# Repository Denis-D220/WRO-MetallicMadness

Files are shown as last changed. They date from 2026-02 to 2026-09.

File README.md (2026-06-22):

# MetallicMadness / ARBIBOT — WRO Future Engineers 2026

ARBIBOT on the WRO Future Engineers field

**MetallicMadness** is a WRO Future Engineers self-driving car project developed for the **WRO 2026 Future Engineers — Self-Driving Cars** challenge. The robot is named **ARBIBOT**. It is an autonomous four-wheel vehicle that combines computer vision, time-of-flight distance sensing, embedded motor control, and a modular software architecture to complete the Open Challenge and Obstacle Challenge tasks.

The project focuses on building a reproducible autonomous vehicle that can drive several laps on the WRO racetrack, follow the correct driving direction, react to red and green traffic signs, avoid moving obstacles, and support parking behavior. The design uses a high-level AI processor for perception and navigation decisions, and a low-level STM32 controller for real-time motor control, sensor acquisition, and encoder feedback.

This repository contains the source code, engineering journal, wiring references, subsystem images, sensor and motor-control documentation, and supporting files required to understand, rebuild, and evaluate the robot.

---

## Team Information

| Item | Information |
|---|---|
| Team name | MetallicMadness |
| Robot name | ARBIBOT |
| Competition | WRO Future Engineers — Self-Driving Cars |
| Institution | Universidad Metropolitana, Caracas |
| Country | Venezuela |
| Team member | Daniel Jose Denis Castillo |
| Team member | Douglas Gabriel Ordaz Yanez |
| Tutor / Coach | Daniel Jose Denis Rodriguez |

### Team Members

**Daniel Jose Denis Castillo** is an Electrical Engineering student at Universidad Metropolitana in Caracas. He has a strong passion for electronics, robotics, Python programming, AI models, and practical problem solving. His work in this project focuses on embedded systems, robot integration, testing, and autonomous behavior.

**Douglas Gabriel Ordaz Yanez** is studying Electrical Engineering and Computer Engineering at Universidad Metropolitana in Caracas. He has a strong interest in software development, game programming, coding logic, and digital systems. His contribution focuses on programming logic, testing, software structure, and implementation support.

**Daniel Jose Denis Rodriguez**, the tutor, is an Electrical Engineer from Universidad Metropolitana with more than 25 years of experience in software engineering, telecommunications, AI, cybersecurity, embedded systems, and technology leadership. His role is to guide the students in project planning, engineering reasoning, documentation, and technical review.

---

## Project Goals

The main goal of ARBIBOT is to create an autonomous self-driving robot that can complete the WRO Future Engineers track using a combination of computer vision, ToF distance sensors, and embedded motor control.

The robot was designed around the following engineering goals:

1. **Autonomous driving:** the vehicle must drive without remote control or wireless assistance during the round.
2. **Stable lane behavior:** the robot must stay aligned with the track walls using distance sensors and heading correction.
3. **Obstacle strategy:** the robot must recognize red and green traffic signs and pass them on the correct side.
4. **Reliable embedded control:** motor, encoder, and sensor operations must be handled by a dedicated STM32 controller.
5. **High-level perception:** the Jetson Orin Nano processes camera input and runs YOLO-based detection models.
6. **Reproducibility:** the repository and engineering journal must allow another team to understand and rebuild the system with reasonable effort.
7. **Iteration and testing:** the project documents failures, design changes, and improvements made during development.

---

## Repository Structure

```text
WRO-MetallicMadness/
├── README.md
├── engineering-journal/
│   ├── README.md
│   ├── engineering-journal.md
│   ├── engineering-journal.pdf
│   └── images/
├── src/
│   ├── NVIDIA/
│   └── STM32F411/
├── schemes/
├── models/
├── t-photos/
├── v-photos/
├── video/
└── other/
```

### Folder Purpose

| Folder | Purpose |
|---|---|
| `engineering-journal/` | Main engineering documentation in Markdown and PDF format, including images and system explanations. |
| `src/NVIDIA/` | Python code running on the NVIDIA Jetson Orin Nano, including vision, navigation, serial communication, and steering control. |
| `src/STM32F411/` | STM32 firmware for motor control, distance sensor acquisition, encoder feedback, IMU reading, and DD-UART command handling. |
| `schemes/` | Wiring diagrams, power diagrams, system block diagrams, and subsystem architecture references. |
| `models/` | CAD, mechanical models, 3D printed parts, AI model notes, or model references used by the project. |
| `t-photos/` | Team photos required for WRO documentation. |
| `v-photos/` | Vehicle photos from all required views: front, rear, left, right, top, and bottom. |
| `video/` | Links or notes for Open Challenge and Obstacle Challenge autonomous driving videos. |
| `other/` | Additional supporting files such as datasheets, testing notes, calibration references, and protocol details. |

---

## Robot Overview

ARBIBOT is a compact 3D-printed autonomous vehicle using rear-wheel drive and front-wheel steering. The mechanical design follows the WRO requirement of a four-wheel vehicle with one driving axle and one steering actuator. The robot uses a custom front steering linkage and a single DC gear motor with an encoder for propulsion.

### Physical Characteristics

| Parameter | Value |
|---|---:|
| Length | 25 cm |
| Width | 15.6 cm |
| Height | 18 cm |
| Weight | 1.35 kg |
| Wheelbase | 13.9 cm |
| Track width | TODO: measure and fill |
| Chassis | 3D printed |
| Drive configuration | Rear-wheel drive |
| Steering | Servo-actuated pushrod steering with tie-rod linkage |

The steering system uses a servo arm to push and pull a linkage connected to the front steering knuckle. Both front wheels are mechanically connected by a tie rod, so the motion of one wheel is transferred to the other. This creates a synchronized front-wheel steering system using only one steering actuator. The geometry is Ackermann-inspired, but it is documented as a custom servo-driven pushrod/tie-rod linkage unless precise steering angle measurements are added later.

The 3D-printed chassis was selected because it allows fast mechanical iteration. Several bumper versions and sensor positions were tested. Early bumper designs created interference with the wheels while turning, so the front structure and sensor mounts were adjusted. The team also tested thinner wheels, but they slipped on the track, so wider wheels with better grip were selected.

---

## Mechanical Design

### Chassis

The robot uses a 3D-printed chassis designed to hold the Jetson Orin Nano, STM32 controller, motor driver, batteries, distance sensors, camera mount, steering system, and wiring. The chassis design prioritizes modularity and easy access to subsystems during testing.

The mechanical structure was developed through iteration. Early versions had issues with sensor height, bumper clearance, and torque transfer. These issues were corrected by modifying the sensor mount height, changing bumper geometry, and improving the drivetrain layout.

### Drive Motor

The drive motor is a **JGY-370B 12V Mini Worm Gear Motor with Encoder**, configured for approximately **150 RPM** no-load speed. It is a double-shaft DC gear motor with Hall encoder feedback.

Key characteristics:

| Item | Value |
|---|---|
| Motor type | DC worm gear motor with encoder |
| Model | JGY-370B |
| Rated voltage | 12 V DC |
| Speed | 150 RPM |
| Encoder type | Hall AB quadrature output |
| Basic pulse count | 11 PPR before gearbox multiplication |
| Encoder voltage | 3.3 V / 5 V |
| Output signal | Square wave AB phase |
| Direction | Reversible CW / CCW |
| Gear material | Metal gears |

The worm gear motor was selected because it provides useful torque for a compact robot and has a self-locking behavior when power is removed. The encoder allows the STM32 to measure wheel movement and RPM. The project originally tested a motor without an encoder, but this limited feedback and made distance-based movement less reliable.

### Steering Actuator

The steering actuator is an **MG996R servo**.

| Parameter | Value |
|---|---|
| Model | MG996R |
| Voltage | 5 V |
| Torque | approximately 9.4 kg·cm at 4.8 V |
| Control | Pololu servo controller |

The steering linkage was tuned by adjusting rod lengths and servo arm geometry. The final adjustments use a screw-based alignment method to modify the distance between linkage points and improve front-wheel alignment. This was necessary to increase turning range and reduce unwanted steering bias.

---

## System Architecture

ARBIBOT uses a two-controller architecture:

1. **NVIDIA Jetson Orin Nano** — high-level perception, vision, navigation logic, and decision making.
2. **STM32F411 Black Pill** — low-level sensor acquisition, motor control, encoder reading, and serial command execution.

This separation allows the robot to keep time-critical motor and sensor operations on the STM32 while the Jetson handles heavier AI and image-processing tasks. This design also improves modularity: the Jetson can send high-level commands, while the STM32 safely executes motor and sensor routines.

```text
Camera + YOLO + Navigation Logic
              │
              ▼
     NVIDIA Jetson Orin Nano
              │  DD-UART over USB/Serial
              ▼
         STM32F411 Black Pill
              │
 ┌────────────┼─────────────┐
 ▼            ▼             ▼
Motor      ToF Sensors     Encoder / IMU
Driver
```

---

## NVIDIA Jetson Orin Nano Subsystem

The Jetson Orin Nano is the high-level processor used for AI inference, camera processing, autonomous decision making, and communication with the STM32. It was selected because it provides enough AI acceleration and computing capacity to run YOLO inference and OpenCV processing in real time while also managing navigation logic.

### Jetson Responsibilities

The Jetson runs:

- Camera capture through a CSI camera pipeline.
- YOLO inference using custom-trained models.
- Red and green pillar detection.
- Blue/orange line and corner detection.
- Lane and wall-following logic.
- Navigation decision logic.
- Command transmission to the STM32 through the custom DD-UART serial protocol.
- Steering commands through a Pololu servo controller.

### Camera

The camera is a **Mini 12.3MP HQ Camera compatible with NVIDIA Jetson boards**, using a **Sony IMX477** sensor and an M12 mount lens. It is connected directly to the Jetson through the MIPI CSI-2 camera connector.

The camera is used for:

- Detecting red and green pillars.
- Detecting blue and orange track lines.
- Estimating the horizontal position of objects.
- Supporting corner detection and driving direction logic.

YOLO is used instead of only color thresholding because the lighting conditions on the field can change. Reflections, shadows, glare, camera exposure, and partial occlusion can make simple HSV thresholds unstable. YOLO provides both object localization and classification, making it more robust for competition environments.

---

## STM32F411 Subsystem

The STM32F411 Black Pill acts as the real-time controller for peripheral devices. Its main purpose is to isolate low-level deterministic tasks from the Jetson so that motor control and sensor reading remain stable even while the Jetson performs heavier vision inference.

### STM32 Responsibilities

The STM32 handles:

- Reading VL53L4CD side distance sensors.
- Reading the front VL53L8CH ToF matrix sensor.
- Managing the I2C sensor bus.
- Using XSHUT pins to initialize multiple VL53L4CD sensors with different addresses.
- Reading motor encoder AB phases.
- Measuring RPM and movement distance.
- Driving the Cytron MD10C motor driver using PWM and direction signals.
- Processing serial commands from the Jetson.
- Returning sensor and motor responses through DD-UART.

The STM32 firmware is organized into modules for protocol handling, motor control, distance sensors, IMU, platform I2C layers, and the main command-dispatch loop.

---

## Sensor Architecture

The robot uses multiple ST time-of-flight distance sensors to measure the distance to walls, obstacles, and front barriers. The sensor system is designed to support wall following, obstacle distance estimation, side correction, and parking behavior.

### Distance Sensors

| Sensor | Quantity | Placement | Purpose |
|---|---:|---|---|
| VL53L4CD | 3 | left front, right front, right rear/middle | Side distance, wall following, side correction, obstacle distance, parking support |
| VL53L8CH | 1 | front bumper / center front | Front matrix distance, barrier detection, corner trigger support |

### Sensor Placement

| Sensor | Location | I2C Address | XSHUT Pin |
|---|---|---|---|
| Left VL53L4CD | Front bumper, left side | 0x52 | PA5 |
| Right-front VL53L4CD | Front bumper, right side | 0x54 | PA7 |
| Right-rear VL53L4CD | Middle of car, between wheels | 0x56 | PB14 |
| Front VL53L8CH | Front bumper / center | 0x52 | Dedicated initialization / bus handling |

The two right-side sensors are used for wall-following and heading correction. The difference between the right-front and right-rear readings indicates whether the robot is parallel to the wall. This helps prevent the robot from drifting across the lane.

The front VL53L8CH is used as a matrix-based distance sensor. It helps detect the front wall and supports corner timing by identifying when the robot is approaching a barrier. The logic uses filtered readings to avoid false triggers from floor cells or isolated noisy readings.

An I2C expansion board is used to simplify wiring, distribute power, and share the I2C bus cleanly between multiple sensors. Multiple VL53L4CD sensors require XSHUT-controlled startup so that the STM32 can assign or activate addresses without bus conflicts.

### Sensor Calibration

The sensors are calibrated using fixed reference distances:

```text
120 cm, 110 cm, 100 cm, 90 cm, 80 cm, 70 cm, 60 cm, 50 cm, 40 cm, 30 cm, 20 cm, 10 cm
```

A Python test script reads all sensors after moving the car to each reference distance. This helps identify offsets, unstable readings, and sensor placement issues. The calibration process is important because small sensor errors can produce steering oscillation or incorrect corner detection.

---

## Motor Driver and Encoder

The robot uses a **Cytron MD10C motor driver** to control the 12 V DC gear motor. The MD10C receives control signals from the STM32 and motor power from the 3S battery system through the BMS.

### MD10C Control

| Signal | Source | Purpose |
|---|---|---|
| PWM | STM32 PA6 / timer channel | Controls motor speed |
| DIR | STM32 GPIO | Controls motor direction |
| GND | STM32 common ground | Shared logic reference |
| VIN | Motor battery / BMS | Motor power input |
| Motor output | DC gear motor | Drives rear axle |

The motor encoder provides AB quadrature feedback to the STM32. The firmware uses encoder pulses to calculate movement distance for move-by-degrees commands and to estimate motor speed in RPM.

---

## Power Architecture

ARBIBOT uses separate power paths for motor power and Jetson/electronics power. This separation reduces the risk that motor noise or high-current motor peaks will reset the Jetson, STM32, sensors, or serial communication.

### Motor Power Path

The motor power path uses **3 × 18650 lithium-ion cells** with a **3S 20A BMS**. The BMS output feeds the Cytron MD10C motor driver directly. The MD10C then powers the 12 V DC gear motor.

| Item | Value |
|---|---|
| Battery type | 18650 lithium-ion cells |
| Cell nominal voltage | 3.7 V |
| Cell capacity | 1200 mAh |
| Series configuration | 3S |
| BMS | 3S 20A BMS |
| Motor driver | Cytron MD10C |
| Motor voltage | 12 V nominal system |

### Jetson and Electronics Power Path

The Jetson uses a separate **Waveshare UPS module** with support for charging and output at the same time. The UPS supports three 18650 lithium batteries and provides the output used to power the Jetson and related electronics.

| Item | Value |
|---|---|
| UPS module | Waveshare UPS module for 3 × 18650 cells |
| Battery support | 3 × 18650 lithium cells |
| Charger | 12.6 V / 2 A |
| Output | Battery series voltage, 5 V 5 A, 3.3 V 300 mA |
| Jetson input | 12 V |
| Camera power | Directly from Jetson CSI camera interface |
| Pololu servo controller power | From the UPS/electronics power path |

### Estimated Power Budget

| Component | Voltage | Typical Current | Peak Current | Notes |
|---|---:|---:|---:|---|
| Jetson Orin Nano | 12 V | workload-dependent | up to high AI workload range | Runs camera, OpenCV, and YOLO inference |
| STM32F411 | 3.3 V / 5 V input | about 10 mA at high CPU speed, depending on peripherals | low | Handles real-time control |
| MG996R steering servo | 5 V | 120–900 mA depending on load | 1.5–2.5 A stall | Steering load depends on wheel friction and linkage geometry |
| JGY-370B drive motor | 12 V | 0.06–0.3 A typical | 1.3–2.0 A stall | Peak occurs during acceleration or stall |
| VL53 sensors | 3.3 V | 15–25 mA each while ranging | sensor-dependent | Multiple ToF sensors active during navigation |
| Camera | Jetson CSI | powered by Jetson | powered by Jetson | Used for YOLO detection |

The expected runtime is approximately **20–30 minutes**, which is higher than the required **3-minute challenge round** duration. The practical design target is not only runtime, but also stable voltage during motor acceleration, steering peaks, and AI inference load.

---

## Software Architecture

The software is divided into high-level Jetson Python modules and low-level STM32 C firmware.

### Jetson Software Modules

| File | Role |
|---|---|
| `main_challenge_01_v4.py` | Open Challenge logic using camera corner detection, heading wall-following, and front ToF matrix corner trigger. |
| `main_challenge_02.py` | Obstacle Challenge logic using pillar YOLO and PDI pass-side steering. |
| `turn_models.py` | Corner detector and line model helper functions. |
| `Pillar_recognition.py` | Converts YOLO results into pillar detections with color, zone, area, and guidance logic. |
| `pillar_counter.py` | Debounced enter/exit counting per pillar color. |
| `pid_line_follower.py` | PID lane controller using difference and single-wall modes. |
| `sensor_distance_v3.py` | Side ToF and front matrix reader/parser. Reduces matrix readings to useful front-barrier distance. |
| `motor_driver.py` | DD-UART motor command wrapper. |
| `servo_controller.py` | Steering servo control through its serial interface. |
| `color_tuning.py` | Per-camera color correction for detection stability. |

### STM32 Firmware Modules

| File | Role |
|---|---|
| `serial_dd_protocol.c/.h` | Parses and validates DD-UART frames, verifies checksum, dispatches commands, and builds responses. |
| `motor_drv.c/.h` | Controls PWM, motor direction, move-by-degrees, encoder counting, and RPM calculation. |
| `sensor_vl53l4cd.c` | Reads side VL53L4CD ToF sensors. |
| `sensor_vl53l7ch.c` | Reads front VL53L7CX/VL53L8 matrix sensor. |
| `sensor_imu.c` | Reads gyro and accelerometer values. |
| `platform.c / platform2.c` | I2C platform layers for the ToF sensors. |
| `main.c` | Main command dispatch and system loop. |

---

## Navigation and Control Strategy

The robot uses a state-machine approach to organize behavior. The main states are:

```text
WAITING_FOR_START
FIRST_SECTOR
STRAIGHT_DRIVE
CORNERING
OBSTACLE_HANDLING
FINISH / STOP
```

### Open Challenge Strategy

In the Open Challenge, the robot drives without red or green pillars. The main navigation goal is to complete three laps while staying inside the lane and correctly detecting corners. The robot uses side ToF sensors to follow the wall and front ToF matrix readings to detect approaching barriers. Camera-based line/corner recognition supports driving direction and corner logic.

### Obstacle Challenge Strategy

In the Obstacle Challenge, the robot must detect red and green traffic signs and pass them on the correct side. The pillar YOLO model returns bounding boxes and classes for **Green_Pillar** and **Red_Pillar**. The robot uses the object class and horizontal location to decide the steering correction.

Rules used by the robot:

- Red pillar: pass on the right side.
- Green pillar: pass on the left side.

The system chooses the nearest relevant pillar using bounding-box area. Larger bounding boxes normally indicate that the pillar is closer. The robot divides the camera image into left, center, and right zones to estimate where the pillar is located relative to the car.

### Control Algorithms

The robot uses several control methods:

| Control method | Purpose |
|---|---|
| PID | Lane and wall-following correction. |
| PDI | Pillar pass-side steering correction. |
| Proportional heading correction | Uses right-front and right-rear ToF sensor difference to keep the robot parallel to the wall. |
| Threshold logic | Detects corner trigger windows and front barrier distance. |
| Sensor fusion | Combines camera, side ToF, and front matrix readings for more reliable navigation. |

---

## DD-UART Serial Protocol

The Jetson communicates with the STM32 using a custom binary protocol called **DD-UART**. This protocol is used to request sensor data, command motor actions, set speed, and stop the robot.

### Frame Format

```text
$ LEN(2 bytes, big-endian) CMD(2 bytes, big-endian) DATA(0..n) CHK(1 byte) \n
```

- `$` is the start byte.
- `LEN` is the total frame length.
- `CMD` is the command ID.
- `DATA` is the optional payload.
- `CHK` is an XOR checksum over the frame content between the start byte and checksum.
- `\n` is the end byte.

### Main Commands

| Command | Name | Payload | Purpose |
|---:|---|---|---|
| `0x0001` | READ_GYRO | none | Read IMU gyro data. |
| `0x0002` | READ_ACCEL | none | Read IMU acceleration data. |
| `0x0003` | READ_FRONT | none | Read front VL53L8/VL53L7 matrix. |
| `0x0004` | FORWARD continuous | none | Drive forward continuously. |
| `0x0005` | REVERSE continuous | none | Drive reverse continuously. |
| `0x0101` | FORWARD by degrees | uint16 degrees | Move forward by encoder-derived distance. |
| `0x0102` | REVERSE by degrees | uint16 degrees | Move reverse by encoder-derived distance. |
| `0x0103` | STOP | none | Stop drive motor. |
| `0x0104` | SET SPEED | uint8 percent | Set motor speed from 0 to 100%. |
| `0x0105` | READ SIDES | none | Read VL53L4CD side sensors. |

Because sensors and motor commands share one serial link, the Jetson avoids blocking motor commands while the sensor thread owns serial reads. Critical commands such as start and stop are sent multiple times to reduce the chance of a dropped frame affecting the run.

---

## Vision and YOLO Models

ARBIBOT uses Ultralytics YOLO with custom-trained weights. The vision system currently uses two model roles:

1. **Pillar model** for the Obstacle Challenge.
2. **Line/corner model** for the Open Challenge.

### Pillar Detection

The pillar model detects:

- `Green_Pillar`
- `Red_Pillar`

The output used by the navigation system includes:

- Class name.
- Bounding-box center X.
- Bounding-box area.
- Confidence.
- Zone: left, center, or right.

The area is used as an approximate closeness signal. The horizontal position is used to calculate steering error and guide the robot to pass the pillar on the correct side.

### Items Still To Be Completed

The following vision information should be added after measurement or review:

- Exact YOLO version.
- Dataset size per model.
- Annotation tool used.
- Training environment.
- Inference FPS on Jetson.
- Average inference time in milliseconds.
- Final confidence thresholds.
- Accuracy or validation metrics.

---

## Testing and Iteration

The robot was developed through multiple software and hardware iterations. The development process included testing drivetrain options, sensor layouts, bumper geometry, motor feedback, serial protocol behavior, and vision model performance.

### Main Iterations

| Version | Description |
|---|---|
| v1 | Initial camera-based corner detection and open-loop center steering. |
| v2 | Added PID wall-following and sensor/front-ToF corner fallbacks. |
| v3 | Tested two-right-sensor wall following and VL53L8 4x4 matrix logic. This version became complex and unstable. |
| v4 | Current Open Challenge base: improved sensor firmware, front-matrix corner trigger, and RF-RR heading wall-follower. |
| Challenge 02 | Current Obstacle Challenge logic: pillar YOLO and PDI pass-side steering. |

### Problems Found and Fixes Applied

| Problem | Cause | Fix |
|---|---|---|
| Robot turned too late and hit front wall | Front matrix readings included floor cells and produced incorrect barrier distance. | Filtered matrix data and used more reliable front-barrier rows. |
| Robot turned too soon | Single noisy matrix cell was interpreted as a wall. | Required at least two valid in-band cells before firing corner trigger. |
| Robot sometimes started incorrectly or reversed | Motor speed command behavior and dropped frames on shared serial bus. | Sent forward command first, then speed commands, with repeated pulses. |
| Stop command sometimes failed | Stop frame dropped during sensor matrix scan. | Repeated stop command to improve reliability. |
| Side sensors returned invalid values | Parser mismatch and heavy YOLO load affected serial timing. | Updated parser and reduced heavy matrix polling until needed. |
| Lane wandered from wall to wall | Distance-only PID did not account for heading. | Added heading correction using right-front minus right-rear sensor difference. |
| Pillar steering full-locked or lost target | PDI gains too high and reaction too late. | Reduced gains, lowered steering clamp, and reacted earlier. |

### Testing Metrics To Add

The following results should be measured and added as the robot improves:

| Metric | Value |
|---|---|
| Best lap time | TODO |
| Average lap time | TODO |
| Open Challenge success rate | TODO |
| Obstacle Challenge success rate | TODO |
| Parking success rate | TODO |
| YOLO FPS | TODO |
| Front-matrix corner trigger distance | approximately 100 cm observed, confirm with tests |
| Wall-follow target gap error | TODO |

---

## Build and Setup Overview

### Hardware Assembly Summary

1. Print and prepare the chassis and sensor mounts.
2. Install the rear drive motor and connect it mechanically to the driven axle.
3. Install the steering servo and connect the pushrod/tie-rod steering linkage.
4. Mount the Jetson Orin Nano securely on the top platform.
5. Mount the STM32F411 and connect the sensor wiring.
6. Install the Cytron MD10C and connect it to the motor battery path.
7. Install the BMS and motor battery pack.
8. Install the Waveshare UPS and Jetson/electronics battery pack.
9. Mount the VL53L4CD and VL53L8CH sensors in their final positions.
10. Mount the camera and verify the field of view.
11. Connect common grounds where required by the electronics architecture.
12. Verify wiring before powering motors.

### Jetson Setup Summary

The Jetson runs the high-level Python software. The setup includes:

- Jetson Linux / Ubuntu environment.
- Python 3 environment.
- OpenCV.
- Ultralytics YOLO.
- PySerial.
- Camera support through GStreamer / CSI pipeline.
- Project Python modules from `src/NVIDIA/`.

Exact OS version, Python version, and package versions should be added to this README once finalized.

### STM32 Setup Summary

The STM32 firmware is built and flashed using the STM32 development environment used by the team. The firmware includes motor driver control, sensor drivers, protocol handling, and command dispatch.

The STM32 must be connected to the Jetson through USB/serial using the configured USART interface. The sensor bus and motor driver pins must match the firmware pin definitions.

### Start Procedure

The intended competition procedure is:

1. Place the robot in the start zone while switched off.
2. Switch on the robot using the allowed power switch.
3. The robot enters a waiting state.
4. At the judge signal, press the start button.
5. The robot begins autonomous driving.
6. The robot stops automatically after completing the challenge or when commanded by its internal logic.

---

## Documentation

The main engineering documentation is available in:

- [`engineering-journal/engineering-journal.md`](engineering-journal/engineering-journal.md)
- [`engineering-journal/engineering-journal.pdf`](engineering-journal/engineering-journal.pdf)

The Engineering Journal contains more detailed explanations of:

- Mechanical design.
- Power architecture.
- Sensor architecture.
- Jetson and STM32 responsibilities.
- YOLO and navigation strategy.
- DD-UART communication.
- Testing failures and improvements.
- Reproducibility notes.

---

## Media Requirements

WRO documentation requires clear evidence of the final robot and its autonomous behavior. The following files should be added as the project progresses:

### Vehicle Photos

Place these in `v-photos/`:

- Front view.
- Rear view.
- Left side view.
- Right side view.
- Top view.
- Bottom view.
- Steering close-up.
- Sensor mounting close-up.
- Motor and encoder close-up.
- Battery and wiring layout.

### Team Photos

Place team photos in `t-photos/`.

### Videos

Place video links or notes in `video/`:

- Open Challenge autonomous run video.
- Obstacle Challenge autonomous run video.

Each video should clearly show the vehicle driving autonomously for at least 30 seconds.

---

## Current Status

The robot currently has a working hardware and software architecture with the following completed or partially completed subsystems:

- 3D-printed chassis.
- Rear-wheel drive motor and encoder system.
- Servo-actuated front steering.
- Jetson Orin Nano high-level controller.
- STM32F411 low-level controller.
- Cytron MD10C motor control.
- VL53L4CD side sensors.
- VL53L8CH front matrix sensor.
- DD-UART protocol between Jetson and STM32.
- YOLO-based red/green pillar detection.
- Camera-assisted line/corner detection.
- PID/PDI-based navigation logic.
- Engineering Journal first complete draft.

Remaining work includes:

- Fill final physical measurements such as track width and wheel diameter.
- Add official robot photos from all required views.
- Add team photo.
- Add final challenge video links.
- Measure final current consumption.
- Add exact Jetson OS, Python version, and library versions.
- Add YOLO training dataset details and performance metrics.
- Add final Open Challenge and Obstacle Challenge test results.
- Improve parking documentation and final parking test metrics.

---

## Engineering Philosophy

The project is built around a simple principle: the robot should be understandable as a complete system, not just a collection of parts. The Jetson, STM32, sensors, motor driver, batteries, software modules, and mechanical chassis all affect each other. A faster motor changes steering behavior. Sensor placement changes the control loop. Power stability affects serial communication and vision inference. Camera detection affects obstacle strategy. The final design must therefore be evaluated as a full engineering system.

The documentation in this repository is intended to show not only what was built, but why decisions were made. The team tested alternatives, identified failures, and improved the design through iteration. This includes changing motors, changing wheels, adjusting bumper geometry, replacing ultrasonic sensors with laser ToF sensors, tuning steering linkage geometry, filtering front matrix sensor readings, and improving serial command reliability.

---

## License and Use

This repository is prepared for educational and competition documentation purposes. The project is part of the WRO Future Engineers learning process and is intended to help demonstrate the engineering work performed by the MetallicMadness team.

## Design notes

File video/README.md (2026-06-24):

# Video

This folder contains video evidence for the **MetallicMadness / ARBIBOT** WRO Future Engineers self-driving car project.

The videos in this folder document real robot behavior during testing and challenge runs. They support the engineering documentation by showing that the robot can move autonomously, follow the track, steer, detect the environment, respond to obstacles, and execute challenge-specific behavior.

---

## Folder Contents

| File | Challenge / Test | Description | Current status |
|---|---|---|---|
| `challenge01.mp4` | Open Challenge / Challenge 01 | Video of ARBIBOT running the first WRO Future Engineers challenge. It shows autonomous driving behavior, steering response, lane behavior, corner handling, and system integration during testing. | Available |
| `challenge02.mp4` | Obstacle Challenge / Challenge 02 | Video of ARBIBOT running the Obstacle Challenge with red and green traffic pillars. It documents pillar detection, pass-side strategy, steering response, and obstacle-handling behavior. | Available |

---

## Video Purpose

The purpose of this folder is to provide visual evidence for:

- autonomous robot movement,
- steering control,
- lane-following behavior,
- corner handling,
- motor control,
- sensor and software integration,
- Open Challenge testing progress,
- Obstacle Challenge red/green pillar behavior,
- and WRO documentation requirements.

Videos are especially important because they show the complete robot operating as a system, not only individual components working separately.

---

## Challenge Videos

## Open Challenge / Challenge 01

File:

```text
challenge01.mp4
```

Description:

```text
ARBIBOT running the first WRO Future Engineers challenge, also known as the Open Challenge.
```

This video should be used as evidence in:

```text
README.md
engineering-journal/WRO_Engineering_Journal_MetallicMadness.md
docs/06-testing-and-tuning.md
```

Recommended Markdown reference from the root `README.md`:

```markdown
[Open Challenge test video](video/challenge01.mp4)
```

Recommended Markdown reference from `docs/06-testing-and-tuning.md`:

```markdown
[Open Challenge test video](../video/challenge01.mp4)
```

Recommended Markdown reference from `engineering-journal/WRO_Engineering_Journal_MetallicMadness.md`:

```markdown
[Open Challenge test video](../video/challenge01.mp4)
```

---

## Obstacle Challenge / Challenge 02

File:

```text
challenge02.mp4
```

Description:

```text
ARBIBOT running the second WRO Future Engineers challenge, also known as the Obstacle Challenge.
```

This video documents obstacle-handling behavior with red and green traffic pillars. It supports the Obstacle Challenge documentation by showing the robot using vision, steering control, and pass-side logic during a real run.

This video should be used as evidence in:

```text
README.md
engineering-journal/WRO_Engineering_Journal_MetallicMadness.md
docs/04-obstacle-strategy.md
docs/06-testing-and-tuning.md
```

Recommended Markdown reference from the root `README.md`:

```markdown
[Obstacle Challenge test video](video/challenge02.mp4)
```

Recommended Markdown reference from `docs/04-obstacle-strategy.md`:

```markdown
[Obstacle Challenge test video](../video/challenge02.mp4)
```

Recommended Markdown reference from `docs/06-testing-and-tuning.md`:

```markdown
[Obstacle Challenge test video](../video/challenge02.mp4)
```

Recommended Markdown reference from `engineering-journal/WRO_Engineering_Journal_MetallicMadness.md`:

```markdown
[Obstacle Challenge test video](../video/challenge02.mp4)
```

---

## Video Documentation Table

| Video | Challenge / Test | Result / Evidence | Notes |
|---|---|---|---|
| `challenge01.mp4` | Open Challenge | Open Challenge behavior evidence | Shows autonomous driving, lane behavior, corner handling, and system integration. |
| `challenge02.mp4` | Obstacle Challenge | Obstacle Challenge behavior evidence | Shows red/green pillar behavior, obstacle strategy, steering response, and vision-based handling. |

---

## Optional Future Videos

The main challenge videos are now present. Optional future videos can be added if the team wants more evidence for debugging, calibration, or reproducibility.

| File | Description |
|---|---|
| `parking-test.mp4` | Optional video showing the robot entering or completing the parking phase. |
| `sensor-test.mp4` | Optional video showing distance sensor behavior during calibration. |
| `motor-test.mp4` | Optional video showing motor, steering, and encoder validation. |
| `video.md` | Optional summary file with links, descriptions, dates, and notes for each video. |

---

## Video Naming Convention

Use lowercase names with hyphens or simple challenge numbers.

Recommended names:

```text
challenge01.mp4
challenge02.mp4
parking-test.mp4
sensor-calibration-test.mp4
motor-command-test.mp4
```

Avoid spaces in filenames because spaces can make links harder to manage in Markdown and GitHub.

---

## Notes for GitHub

Video files can become large. If GitHub rejects a video upload because of file size limits, use one of these options:

1. Compress the video.
2. Use Git LFS.
3. Upload the video to YouTube or another public video platform.
4. Add the public video link in this README and in `video.md`.

If an external video link is used, include:

- video title,
- challenge name,
- date,
- short description,
- and whether the run was a full success, partial success, or test run.

Recommended Git LFS setup for video files:

```bash
git lfs install
git lfs track "*.mp4"
git add .gitattributes
```

---

## Update Policy

When a new video is added:

1. Place the video file in this folder.
2. Add the video name and description to this README.
3. Reference the video from the root `README.md`.
4. Reference the video from the relevant documentation file in `docs/`.
5. If the video is used as official evidence, also reference it from the Engineering Journal.

---

## Current Status

The folder currently includes video evidence for both main WRO Future Engineers challenges:

```text
challenge01.mp4
challenge02.mp4
```

`challenge01.mp4` documents the Open Challenge.  
`challenge02.mp4` documents the Obstacle Challenge.

Additional parking, sensor, or motor validation videos are optional future evidence files.

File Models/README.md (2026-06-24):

# Models

This folder contains the trained machine-learning model files and CAD model references used by **MetallicMadness / ARBIBOT** for the WRO 2026 Future Engineers autonomous driving challenges.

The `.pt` files are used by the NVIDIA Jetson Orin Nano for visual perception. They detect traffic pillars, colored track lines, and corner/line features that support the robot's navigation logic.

The `cad/` folder contains the current 3D chassis design exported as STL files. These CAD files support mechanical reproducibility of the robot.

---

## Folder Contents

| File / folder | Description | Current status |
|---|---|---|
| `best_model_1.pt` | Earlier YOLO11n pillar/object detection checkpoint. Kept for comparison and fallback testing. | Archived / backup |
| `best_model_v2.pt` | Active YOLO11n pillar detection model used for the Obstacle Challenge. | Active |
| `Best_Model_Corner.pt` | Active YOLO11n corner/line detection model used for the Open Challenge. | Active |
| `cad/` | CAD folder containing the three-layer chassis STL design. | Active mechanical reference |

---

## CAD Chassis Design

The `cad/` folder contains the current 3D-printable chassis design for ARBIBOT. The chassis is organized as a three-layer structure so the robot can separate the bottom mechanical base, middle support layer, and top/electronics mounting layer.

| CAD file | Purpose |
|---|---|
| `cad/Chasis_Bottom.stl` | Bottom chassis layer. Supports the lower mechanical structure, wheel/motor layout, and base mounting geometry. |
| `cad/Chasis_Middle.stl` | Middle chassis layer. Provides intermediate support and spacing between the lower mechanical system and upper electronics layout. |
| `cad/Chasis_Top.stl` | Top chassis layer. Supports upper electronics, mounting points, and overall structure closure. |

The filename uses `Chasis` to match the current repository files. If the files are renamed later to `Chassis_*`, this README and any links in the Engineering Journal should be updated in the same commit.

### CAD Design Notes

The three-layer chassis helps the robot remain reproducible because each major structural level is stored as an STL file. The design supports:

- rear-wheel drive motor installation,
- steering servo and linkage placement,
- wheel and axle clearance,
- sensor and bumper mounting,
- electronics placement,
- battery and wiring organization,
- and future mechanical iteration.

Related documentation:

```text
docs/01-mechanical-design.md
engineering-journal/WRO_Engineering_Journal_MetallicMadness.md
v-photos/motor-stearing.png
v-photos/car-bottom.png
```

---

## Active Model Roles

| Model | Role | Classes | Used by |
|---|---|---|---|
| `best_model_v2.pt` | Pillar detection for the Obstacle Challenge | `Green_Pillar`, `Red_Pillar` | `main_challenge_02.py`, `Pillar_recognition.py` |
| `Best_Model_Corner.pt` | Track line / corner support for the Open Challenge | `Blue_line`, `Orange_line` | `main_challenge_01_v4.py`, `turn_models.py` |
| `best_model_1.pt` | Earlier pillar/object detection checkpoint kept for comparison | `Green_Pillar`, `Red_Pillar` | Legacy / fallback reference |

---

## Model Type

All current trained detection models are based on:

```text
Ultralytics YOLO11 nano
YOLO architecture: YOLO11n
Base model: yolo11n.pt
```

YOLO11n was selected because it gives a good balance between inference speed and detection quality on the Jetson Orin Nano. Larger models could improve accuracy, but they would also increase latency and could reduce the responsiveness of the camera, navigation, and serial-sensor loops.

---

## Dataset Summary

| Dataset | Related model file | Classes | Split | Image count |
|---|---|---|---|---:|
| Pillar dataset | `best_model_v2.pt` / `best_model_1.pt` | `Green_Pillar`, `Red_Pillar` | 70% train / 20% validation / 10% test | 100 images |
| Corner / line dataset | `Best_Model_Corner.pt` | `Blue_line`, `Orange_line` | 70% train / 20% validation / 10% test | 180 images |

---

## Training Procedure

Both YOLO models were trained with the same general pipeline. The Roboflow project and class labels differ between the pillar model and the corner/line model.

1. **Data collection**  
   Images were captured from the competition track using the robot's own camera. This keeps the training data close to the real deployment camera angle, lens behavior, and lighting conditions.

2. **Annotation**  
   Images were uploaded to Roboflow and manually labeled image by image using bounding boxes.

3. **Dataset split**  
   The dataset was split as:

   ```text
   70% training
   20% validation
   10% test
   ```

4. **Export format**  
   Datasets were exported from Roboflow in YOLOv11 format, including images, YOLO `.txt` label files, and `data.yaml`.

5. **Training**  
   Training was performed with Ultralytics YOLO using `yolo11n.pt` as the pretrained base model.

   ```python
   from ultralytics import YOLO

   model = YOLO("yolo11n.pt")
   model.train(data=".../data.yaml", epochs=15, imgsz=640)
   ```

6. **Validation and testing**  
   The resulting `best.pt` model was tested on held-out images. After visual verification, the model was copied into the `Models/` folder and used by the Jetson challenge scripts.

---

## Training Configuration

| Field | Value |
|---|---|
| Model family | Ultralytics YOLO |
| Architecture | YOLO11n |
| Base weights | `yolo11n.pt` |
| Annotation tool | Roboflow |
| Labeling method | Manual bounding-box labeling by the team |
| Export format | YOLOv11 |
| Dataset split | 70% train / 20% validation / 10% test |
| Training environment | PC/GPU environment |
| Jetson role | Inference only |
| Epochs | 15 |
| Image size | 640 x 640 |
| Numeric mAP / validation score | Not recorded in the current repository notes |
| Runtime speed on Jetson | Approximately 60 FPS during testing |

---

## How the Models Are Used

The Jetson camera captures frames using OpenCV/GStreamer. The challenge script sends those frames to an Ultralytics YOLO model. The detections are converted into navigation decisions.

General flow:

```text
Camera frame
    -> YOLO11n model
    -> detection boxes / classes / confidence
    -> navigation logic
    -> steering and motor commands
```

Obstacle Challenge flow:

```text
Camera frame
    -> pillar YOLO model
    -> Green_Pillar / Red_Pillar
    -> screen zone + bounding-box area
    -> pass-side steering logic
```

Open Challenge flow:

```text
Camera frame
    -> corner/line YOLO model
    -> Blue_line / Orange_line
    -> corner or line feature
    -> corner direction / turn support
```

---

## Detection Classes

### Pillar model

```text
Green_Pillar
Red_Pillar
```

### Corner / line model

```text
Blue_line
Orange_line
```

---

## Current Confidence Thresholds

The current working confidence thresholds are:

```text
Pillar confidence threshold: 0.30
Corner line confidence threshold: 0.48
```

These values are also documented in:

```text
docs/07-calibration-procedures.md
```

They should be re-tested after major changes to:

- camera angle,
- camera lens or focus,
- lighting conditions,
- model weights,
- dataset augmentation,
- camera color tuning,
- or final field setup.

---

## Model Metadata Table

| Field | `best_model_1.pt` | `best_model_v2.pt` | `Best_Model_Corner.pt` |
|---|---|---|---|
| Model type | YOLO11n | YOLO11n | YOLO11n |
| Role | Earlier pillar/object checkpoint | Active pillar model | Active corner/line model |
| Dataset | Pillar dataset | Pillar dataset | Corner / line dataset |
| Dataset size | 100 images | 100 images | 180 images |
| Classes | `Green_Pillar`, `Red_Pillar` | `Green_Pillar`, `Red_Pillar` | `Blue_line`, `Orange_line` |
| Image size | 640 x 640 | 640 x 640 | 640 x 640 |
| Epochs | 15 | 15 | 15 |
| Inference FPS on Jetson | Approximately 60 FPS pipeline speed | Approximately 60 FPS pipeline speed | Approximately 60 FPS pipeline speed |
| Active challenge script | Legacy / fallback reference | `main_challenge_02.py` | `main_challenge_01_v4.py` |
| Supporting module | `Pillar_recognition.py` | `Pillar_recognition.py` | `turn_models.py` |
| Status | Archived / backup | Active | Active |

---

## Related Source Files

The models are used by these project files:

```text
src/main_challenge_01_v4.py
src/main_challenge_02.py
src/Pillar_recognition.py
src/turn_models.py
src/color_tuning.py
```

Related documentation:

```text
docs/01-mechanical-design.md
docs/03-software-architecture.md
docs/04-obstacle-strategy.md
docs/06-testing-and-tuning.md
docs/07-calibration-procedures.md
docs/10-risk-register.md
engineering-journal/WRO_Engineering_Journal_MetallicMadness.md
```

Related media and CAD evidence:

```text
Models/cad/Chasis_Bottom.stl
Models/cad/Chasis_Middle.stl
Models/cad/Chasis_Top.stl
v-photos/car-bottom.png
v-photos/motor-stearing.png
```

---

## Naming Convention

Recommended naming convention for future model files:

```text
pillar_yolo_v1.pt
pillar_yolo_v2.pt
corner_yolo_v1.pt
corner_yolo_v2.pt
```

Recommended naming convention for future CAD files:

```text
chassis_bottom_v1.stl
chassis_middle_v1.stl
chassis_top_v1.stl
```

The current filenames are kept because they match the existing project history and may be referenced by the repository. If a model or CAD file is renamed, the code and documentation must be updated in the same commit.

---

## Version Control Note

`.pt` model files can be large. If GitHub rejects a model file because of file size limits, use Git LFS.

Recommended Git LFS setup:

```bash
git lfs install
git lfs track "*.pt"
git add .gitattributes
```

Then add the models normally:

```bash
git add Models/*.pt
```

STL files can also become large. If GitHub rejects the CAD files, track them with Git LFS too:

```bash
git lfs track "*.stl"
git add .gitattributes
```

---

## Security Note

Do not commit Roboflow API keys or other private tokens to the repository. Use an environment variable instead.

Recommended pattern:

```python
import os
from roboflow import Roboflow

rf = Roboflow(api_key=os.environ["ROBOFLOW_API_KEY"])
```

Recommended `.gitignore` entry:

```text
.env
```

---

## Update Policy

When a model changes:

1. Add the new `.pt` file to this folder.
2. Update the Python script that loads the model.
3. Update this README with the filename, classes, role, and status.
4. Record confidence threshold changes in `docs/07-calibration-procedures.md`.
5. Record test results in `docs/06-testing-and-tuning.md`.
6. Keep old models only if they are useful for comparison or rollback.

When the CAD chassis changes:

1. Add the new `.stl` files to `Models/cad/`.
2. Update this README with the new filenames and purpose.
3. Update `docs/01-mechanical-design.md` if the chassis geometry or layer structure changes.
4. Update the Engineering Journal if the CAD design is part of the final reproducibility package.
5. Keep older CAD files only if they document an important design iteration.

---

## Current Status

The folder includes three trained YOLO11n checkpoints:

```text
best_model_1.pt
best_model_v2.pt
Best_Model_Corner.pt
```

The active challenge models are:

```text
Obstacle Challenge: best_model_v2.pt
Open Challenge: Best_Model_Corner.pt
```

The CAD folder includes the current three-layer chassis STL design:

```text
cad/Chasis_Bottom.stl
cad/Chasis_Middle.stl
cad/Chasis_Top.stl
```

The remaining improvement for this folder is optional: record future numeric validation metrics, such as mAP, precision, and recall, if those values are exported from Ultralytics or Roboflow.

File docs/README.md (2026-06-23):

# Docs

This folder contains the main engineering documentation for the **MetallicMadness / ARBIBOT** WRO Future Engineers self-driving car project.

The documents explain the robot design in a structured way: mechanical design, power architecture, sensors, software, obstacle strategy, engineering decisions, testing, calibration, bill of materials, and risk management.

These documents complement the root `README.md`, the Engineering Journal, the diagrams in `schemes/`, the robot photos in `v-photos/`, the trained models in `Models/`, and the challenge videos in `video/`.

---

## Folder Contents

| File | Description | Current status |
|---|---|---|
| `01-mechanical-design.md` | Mechanical design documentation, including chassis, dimensions, drivetrain, steering system, motor selection, wheels, bumper design, mechanical iterations, and known mechanical failure modes. | Updated with current track width and mechanical measurements. |
| `02-power-and-sensor-architecture.md` | Power and sensor architecture, including motor power, Jetson/electronics power, BMS, UPS, current estimates, grounding, VL53 sensor placement, I2C wiring, XSHUT control, and sensor calibration notes. | Updated with current two-battery power design and confirmed sensor address map. |
| `03-software-architecture.md` | Software architecture for Jetson and STM32, including Python modules, STM32 firmware responsibilities, DD-UART command protocol, state machine, sensor processing, motor control, and challenge control flow. | Updated with YOLO11n, current model classes, dataset sizes, and runtime notes. |
| `04-obstacle-strategy.md` | Obstacle Challenge strategy, including red/green pillar behavior, YOLO detection pipeline, nearest-pillar selection, PDI steering control, lane recovery, edge cases, and tuning notes. | Updated with current obstacle result and confirmed model classes. |
| `05-systems-thinking-decisions.md` | Engineering decision record explaining why major design choices were made, what alternatives were rejected, and how failures changed the robot design. | Updated with final mechanical values and current system decisions. |
| `06-testing-and-tuning.md` | Testing and tuning documentation, including test-run logs, lap-time templates, success-rate calculation, failure analysis, motor tests, sensor tests, vision tests, obstacle tests, and tuning parameters. | Updated with current lap times, success rates, YOLO metrics, and known test results. |
| `07-calibration-procedures.md` | Calibration procedures for camera alignment, YOLO confidence, screen zones, ToF thresholds, front matrix trigger, servo center, steering limits, motor speed, encoder validation, and battery logging. | Updated with known calibration values; detailed raw calibration logs remain future measurement records. |
| `09-bill-of-materials.md` | Bill of Materials documenting the main mechanical, electrical, power, compute, sensor, motor, and communication components, including function, voltage, estimated current, and interface. | Updated with current component currents, power domains, and track width. |
| `10-risk-register.md` | Risk register and failure-mode documentation, including glare, bad pillar detection, sensor noise, UART timeout, motor blocking, weak battery, stop-command failure, wheel slip, steering misalignment, and parking risks. | Updated with current sensor address-map mitigation and power-risk status. |

---

## Recommended Reading Order

```text
01-mechanical-design.md
02-power-and-sensor-architecture.md
03-software-architecture.md
04-obstacle-strategy.md
05-systems-thinking-decisions.md
06-testing-and-tuning.md
07-calibration-procedures.md
09-bill-of-materials.md
10-risk-register.md
```

---

## Current Confirmed Project Values

| Topic | Current value |
|---|---|
| Vehicle length | 25.0 cm |
| Vehicle width | Approximately 16.0 cm outside wheel-to-wheel |
| Vehicle height | 18.0 cm |
| Vehicle weight | 1.35 kg |
| Wheelbase | 13.9 cm |
| Track width | 13.5 cm center-to-center |
| Wheel width | 2.5 cm |
| Drive system | Rear-wheel drive using JGY-370B 12 V worm gear motor with encoder |
| Steering | MG996R servo with pushrod/tie-rod front steering linkage |
| Main compute | NVIDIA Jetson Orin Nano |
| Low-level controller | STM32F411 Black Pill |
| Vision models | Ultralytics YOLO11n |
| Pillar classes | `Green_Pillar`, `Red_Pillar` |
| Corner/line classes | `Blue_line`, `Orange_line` |
| Pillar dataset | 100 images |
| Corner/line dataset | 180 images |
| Jetson YOLO runtime | Approximately 60 FPS |
| Best Open Challenge time | 1:05 / 65 seconds |
| Average Open Challenge time | 1:10 / 70 seconds |
| Open Challenge success rate | 80% |
| Obstacle Challenge success rate | 50% |
| Parking success rate | N/A |
| Front matrix address | VL53L8CX on I2C1 at 0x52 8-bit / 0x29 7-bit |
| Side sensor addresses | VL53L4CD sensors on I2C2: LEFT 0x52 PA5, RIGHT_FRONT 0x54 PA7, RIGHT_REAR 0x56 PB14 |

---

## Related Folders

| Folder | Purpose |
|---|---|
| `../schemes/` | Architecture, full wiring, power distribution, and sensor placement diagrams. |
| `../v-photos/` | Real robot photos, including front/back/left/right/top/bottom views, front bumper, motor, and steering images. |
| `../t-photos/` | Team photos. |
| `../video/` | Challenge videos and test-run evidence. |
| `../Models/` | YOLO11n model checkpoints and model documentation. |
| `../other/protocol/` | DD-UART protocol documentation and protocol reference files. |
| `../src/` | Jetson Python code and STM32-related source files. |
| `../engineering-journal/` | Main engineering journal in Markdown/PDF form. |

---

## Important Related Files

| File | Relationship |
|---|---|
| `../README.md` | Main project overview. |
| `../engineering-journal/WRO_Engineering_Journal_MetallicMadness.md` | Main Engineering Journal. |
| `../engineering-journal/WRO_Engineering_Journal_MetallicMadness.pdf` | PDF version of the Engineering Journal. |
| `../schemes/arbibot_2026_electronics_and_control_architecture.png` | High-level electronics and control architecture diagram. |
| `../schemes/full-wiring-diagram.png` | Complete wiring reference. |
| `../schemes/power-distribution-diagram.png` | Power-domain reference. |
| `../schemes/sensor-placement-diagram.png` | Physical sensor layout reference. |
| `../other/protocol/dd-uart-protocol.md` | Detailed serial protocol used between Jetson and STM32. |
| `../video/challenge01.mp4` | Open Challenge video evidence. |

---

## Documentation Status

The documentation set is currently updated with the latest confirmed ARBIBOT information. Some raw calibration/test tables intentionally remain as future measurement records where detailed numeric logs were not captured. These are not blocking documentation items; they are evidence-improvement opportunities.

| Document | Status |
|---|---|
| `01-mechanical-design.md` | Current technical draft updated. |
| `02-power-and-sensor-architecture.md` | Current technical draft updated. |
| `03-software-architecture.md` | Current technical draft updated. |
| `04-obstacle-strategy.md` | Current technical draft updated. |
| `05-systems-thinking-decisions.md` | Current technical draft updated. |
| `06-testing-and-tuning.md` | Current technical draft updated with available metrics. |
| `07-calibration-procedures.md` | Current calibration guide updated with known values. |
| `09-bill-of-materials.md` | Current BOM updated. |
| `10-risk-register.md` | Current risk register updated. |

---

## Update Policy

When the robot changes, update the documentation that is affected.

| Change | Documents to update |
|---|---|
| Steering linkage changed | `01-mechanical-design.md`, `07-calibration-procedures.md`, `10-risk-register.md` |
| Battery or power wiring changed | `02-power-and-sensor-architecture.md`, `09-bill-of-materials.md`, `10-risk-register.md` |
| Sensor position changed | `02-power-and-sensor-architecture.md`, `07-calibration-procedures.md`, `schemes/sensor-placement-diagram.png` |
| YOLO model changed | `03-software-architecture.md`, `04-obstacle-strategy.md`, `07-calibration-procedures.md`, `../Models/README.md` |
| Motor command protocol changed | `03-software-architecture.md`, `../other/protocol/dd-uart-protocol.md`, `10-risk-register.md` |
| New test result recorded | `06-testing-and-tuning.md` |
| New failure discovered | `10-risk-register.md`, `06-testing-and-tuning.md` |

---

## Commit Recommendation

```bash
git add docs/*.md

git commit -m "docs: refresh engineering documentation with current robot data"

git push
```

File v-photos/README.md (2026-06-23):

# Vehicle Photos

This folder contains the vehicle photo evidence for the **MetallicMadness / ARBIBOT** WRO 2026 Future Engineers project.

The images document the robot from all required external views and include additional close-up photos of important mechanical and sensor assemblies. These photos support the Engineering Journal and make the robot design easier to understand and reproduce.

---

## Photo Inventory

| File | View / Purpose | Description |
|---|---|---|
| `car-front.png` | Front view | Shows the front side of ARBIBOT, including the front bumper and front sensor area. |
| `car-back.png` | Rear view | Shows the rear side of the vehicle and the rear wheel arrangement. |
| `car-left.png` | Left side view | Shows the left side of the robot, chassis profile, wheel placement, and side clearance. |
| `car-right.png` | Right side view | Shows the right side of the robot, including the side where wall-following sensors are used. |
| `car-top.png` | Top view | Shows the general layout of the robot from above, including chassis footprint and component placement. |
| `car-bottom.png` | Bottom view | Shows the underside of the vehicle, including the chassis base, wheel layout, drive axle, motor position, and steering layout. |
| `front-bumper.png` | Front sensor close-up | Shows the front bumper and sensor mounting area. This image documents the front ToF sensor placement and bumper design. |
| `motor-steering.png` | Motor and steering mechanism | Shows the robot chassis with the installed rear drive motor, rear axle, wheels, steering servo, steering linkage, and front wheel steering assembly. |
| `motor.png` | Motor component reference | Shows the JGY-370B worm gear DC motor with encoder used as the drive motor reference component. |

---

## Main Vehicle Views

The six main vehicle views are:

```text
car-front.png
car-back.png
car-left.png
car-right.png
car-top.png
car-bottom.png
```

Together, these images document the complete external shape of the robot and verify the physical layout used during testing.

---

## Mechanical Close-Ups

The additional mechanical close-up images are:

```text
front-bumper.png
motor-steering.png
motor.png
```

These images are included because they document important engineering decisions:

- `front-bumper.png` shows the front sensor and bumper layout.
- `motor-steering.png` shows the installed drive motor, rear axle, steering servo, and linkage system in the actual robot chassis.
- `motor.png` shows the motor component used for the drive system.

---

## Notes for the Engineering Journal

The Engineering Journal can reference these files when describing:

- Vehicle dimensions and chassis layout.
- Rear-wheel drive motor installation.
- Steering servo and linkage design.
- Sensor placement and front bumper design.
- Mechanical iteration and reproducibility.

Recommended image references:

```markdown
![Front view of ARBIBOT](../v-photos/car-front.png)

![Bottom view of ARBIBOT](../v-photos/car-bottom.png)

![Front bumper and sensor mount](../v-photos/front-bumper.png)

![Motor and steering mechanism](../v-photos/motor-steering.png)

![Drive motor reference](../v-photos/motor.png)
```

---

## File Format

All images in this folder are stored as `.png` files for consistent GitHub rendering and stable references from the Engineering Journal.

---

## Update Policy

When the vehicle design changes, update this folder with new photos and update this README if:

- A new sensor is added or moved.
- The steering linkage changes.
- The motor or drivetrain changes.
- The chassis geometry changes.
- A clearer close-up image becomes available.
- A filename changes.

Do not remove older photos if they document an important design iteration unless the Engineering Journal no longer references them.

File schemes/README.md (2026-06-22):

# Schemes

This folder contains the main engineering diagrams for the **MetallicMadness / ARBIBOT** WRO Future Engineers self-driving car project.

The purpose of this folder is to make the robot easier to understand, reproduce, debug, and evaluate. These diagrams show how the main electronic, power, sensor, and control subsystems are connected.

## Folder contents

| File | Description |
|---|---|
| `arbibot_2026_electronics_and_control_architecture.png` | High-level architecture diagram showing the Jetson AI/vision domain, STM32 low-level control domain, sensor bus, drive system, power domains, and sensor placement overview. |
| `full-wiring-diagram.png` | Complete wiring diagram showing batteries, BMS, UPS, Jetson, STM32, motor driver, motor encoder, servo controller, distance sensors, I2C expansion board, and communication lines. |
| `power-distribution-diagram.png` | Power architecture diagram showing the separated motor power path and electronics/Jetson power path, including batteries, BMS, UPS, voltage rails, current estimates, and safety notes. |
| `sensor-placement-diagram.png` | Sensor location diagram showing the physical placement and sensing purpose of the VL53L4CD sensors, VL53L8CH front matrix sensor, IMX477 camera, IMU, and motor encoder. |

## Diagram purpose

### Electronics and control architecture

The architecture diagram explains the overall system organization:

- NVIDIA Jetson Orin Nano for AI, camera processing, YOLO inference, and navigation decisions.
- STM32F411 Black Pill for low-level motor control, encoder reading, distance sensor acquisition, and real-time I/O.
- Cytron MD10C motor driver for the rear-wheel drive motor.
- Pololu servo controller for steering.
- VL53 time-of-flight sensors for wall following, obstacle distance, side correction, and front barrier detection.
- Separate motor and electronics power domains.

### Full wiring diagram

The full wiring diagram is the main reference for rebuilding the electrical system. It shows:

- battery connections,
- BMS and UPS wiring,
- motor driver wiring,
- STM32 pin connections,
- UART/USB serial communication,
- I2C sensor wiring,
- XSHUT control lines,
- encoder feedback,
- servo controller wiring,
- and common ground requirements.

### Power distribution diagram

The power distribution diagram explains how power flows through the robot. It documents the separation between:

1. **Drive power domain**  
   High-current path for the motor battery, BMS, Cytron MD10C, and DC gear motor.

2. **Electronics / compute power domain**  
   Regulated power path for the Jetson Orin Nano, camera, Pololu servo controller, and low-current electronics.

This separation reduces the risk of voltage drops, brownouts, sensor instability, UART errors, and resets caused by motor current spikes.

### Sensor placement diagram

The sensor placement diagram documents where the sensors are mounted on the robot and why they are positioned there.

Main sensor roles:

- **Front-center VL53L8CH**: front matrix distance sensor for obstacle and front-barrier detection.
- **Left VL53L4CD**: left/front distance sensing.
- **Right-front VL53L4CD**: right wall distance sensing.
- **Right-rear VL53L4CD**: heading correction by comparing front and rear right-side distances.
- **IMX477 camera**: red/green pillar detection, line/corner detection, and visual navigation.
- **Motor encoder**: wheel odometry and motor feedback.

## Naming convention

Diagram files should use lowercase names with hyphens where possible.

Recommended final names:

```text
arbibot_2026_electronics_and_control_architecture.png
full-wiring-diagram.png
power-distribution-diagram.png
sensor-placement-diagram.png
```

If source or editable versions are added later, place them in this same folder using a clear suffix:

```text
full-wiring-diagram.drawio
power-distribution-diagram.svg
sensor-placement-diagram-editable.pptx
```

## How these diagrams relate to the documentation

These diagrams are referenced from:

```text
README.md
engineering-journal/engineering-journal.md
docs/02-power-and-sensor-architecture.md
docs/03-software-architecture.md
docs/04-obstacle-strategy.md
```

Example Markdown reference from a file inside `docs/`:

```markdown
![Full wiring diagram](../schemes/full-wiring-diagram.png)
```

Example Markdown reference from the root `README.md`:

```markdown
![Full wiring diagram](schemes/full-wiring-diagram.png)
```

Example Markdown reference from `engineering-journal/engineering-journal.md`:

```markdown
![Power distribution diagram](../schemes/power-distribution-diagram.png)
```

## Update policy

When the robot wiring or sensor placement changes, update the relevant diagram immediately. The diagrams should match the actual robot hardware used for testing and competition.

Recommended update order:

1. Update the physical robot wiring or sensor placement.
2. Update the matching diagram in this folder.
3. Update the related documentation in `docs/` or `engineering-journal/`.
4. Commit all related changes together.

## Notes

- All grounds must share a valid common reference where required by signal communication.
- High-current motor wiring should be physically separated from sensitive UART and I2C wiring where possible.
- The final competition wiring should be verified against `full-wiring-diagram.png`.
- The final power design should be verified against `power-distribution-diagram.png`.
- The final physical sensor positions should be verified against `sensor-placement-diagram.png`.

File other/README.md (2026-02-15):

# Other – Technical Documentation

This folder contains additional technical documentation required to understand, reproduce, and maintain the Metallic-Madness WRO 2026 vehicle system.

It includes:

- Hardware component datasheets
- Communication protocol diagrams
- Electrical references
- System documentation supporting the STM32 and Jetson architecture

This folder serves as the technical backbone of the project and ensures:

- Full hardware traceability
- Component verification
- Compliance with WRO documentation requirements
- Engineering transparency

Subfolders:

- `datasheet/` ? Official manufacturer documentation for all major components
- `flowchat/` ? Communication protocol flow diagrams and UART protocol definition

All documents stored here are official reference materials used during development.

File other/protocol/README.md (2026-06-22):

# Protocol

This folder contains communication protocol documentation for the **MetallicMadness / ARBIBOT** WRO Future Engineers self-driving car project.

The main purpose of this folder is to document how the robot’s high-level controller and low-level controller communicate. In ARBIBOT, the NVIDIA Jetson Orin Nano runs AI, camera processing, YOLO inference, and navigation logic, while the STM32F411 handles motor control, sensor acquisition, encoder reading, and low-level I/O.

The protocol documentation in this folder makes the communication layer easier to understand, debug, reproduce, and extend.

## Folder contents

| File | Description |
|---|---|
| `dd-uart-protocol.md` | Main DD-UART protocol documentation. It explains the frame format, length field, checksum calculation, command IDs, payload formats, response examples, validation rules, Python reference code, STM32 validation logic, serial ownership rules, and test checklist. |
| `UART Protocol with Length and Checksum.pdf` | Original reference document for the UART frame structure, length field, checksum method, command examples, and validation approach. Keep this file if it is part of the project history or protocol design reference. |

## DD-UART protocol summary

ARBIBOT uses a framed binary UART protocol between the Jetson and the STM32.

Frame format:

```text
[START][LENGTH][COMMAND][DATA][CHECKSUM][END]
```

Expanded view:

```text
$  LEN_H  LEN_L  CMD_H  CMD_L  DATA...  CHK  \n
```

Field summary:

| Field | Size | Description |
|---|---:|---|
| `START` | 1 byte | ASCII `$`, marks the beginning of the frame |
| `LENGTH` | 2 bytes | Total frame length, big-endian |
| `COMMAND` | 2 bytes | Command ID, big-endian |
| `DATA` | 0 or more bytes | Optional command payload |
| `CHECKSUM` | 1 byte | XOR checksum over `LENGTH + COMMAND + DATA` |
| `END` | 1 byte | ASCII newline `\n`, marks the end of the frame |

Minimum frame length:

```text
7 bytes
```

## Current command groups

The DD-UART protocol is used for:

- reading IMU gyro data,
- reading IMU accelerometer data,
- reading the front VL53L8CH / VL53L7CX-style matrix sensor,
- reading side VL53L4CD distance sensors,
- commanding the motor forward,
- commanding the motor reverse,
- stopping the motor,
- setting motor speed,
- moving forward by encoder degrees,
- moving reverse by encoder degrees.

## Active command IDs

| Command ID | Name | Purpose |
|---:|---|---|
| `0x0001` | `READ_GYRO` | Read IMU gyro values |
| `0x0002` | `READ_ACCEL` | Read IMU accelerometer values |
| `0x0003` | `READ_FRONT` | Read front ToF matrix sensor |
| `0x0004` | `FORWARD_CONTINUOUS` | Start continuous forward motor motion |
| `0x0005` | `REVERSE_CONTINUOUS` | Start continuous reverse motor motion |
| `0x0101` | `FORWARD_DEGREES` | Move forward by encoder degrees |
| `0x0102` | `REVERSE_DEGREES` | Move reverse by encoder degrees |
| `0x0103` | `STOP` | Stop the motor |
| `0x0104` | `SET_SPEED` | Set motor speed percentage |
| `0x0105` | `READ_SIDES` | Read right-front, right-rear, and left VL53L4CD sensors |

## Example frames

### STOP

```text
24 00 07 01 03 05 0A
```

Meaning:

```text
START    = 24
LENGTH   = 00 07
COMMAND  = 01 03
CHECKSUM = 05
END      = 0A
```

### SET_SPEED 80%

```text
24 00 08 01 04 50 5D 0A
```

Meaning:

```text
COMMAND = 0x0104
DATA    = 0x50 = 80 decimal
```

### FORWARD continuous

```text
24 00 07 00 04 03 0A
```

Meaning:

```text
COMMAND = 0x0004
DATA    = none
```

## Related robot software

This protocol is used by both Jetson Python code and STM32 firmware.

Relevant areas:

```text
src/motor_driver.py
src/sensor_distance_v3.py
src/main_challenge_01_v4.py
src/main_challenge_02.py
STM32 firmware serial protocol files
STM32 motor driver files
STM32 sensor driver files
```

## Important implementation rules

1. **Only one process or thread should own serial reads.**  
   Multiple readers can steal each other’s response frames.

2. **Critical commands should be repeated.**  
   Commands such as `STOP` should be pulsed several times because a single frame can be dropped or delayed during heavy serial traffic.

3. **The camera loop should not be blocked by motor communication.**  
   Blocking motor command waits can reduce YOLO detection timing and cause missed pillar detections.

4. **All frames must be validated.**  
   The parser should reject invalid start bytes, invalid end bytes, length mismatch, and checksum mismatch.

5. **Protocol changes must be documented.**  
   If a command ID, payload format, or response format changes in firmware, update `dd-uart-protocol.md`.

## Recommended future files

The following files can be added later if needed:

| File | Purpose |
|---|---|
| `dd-uart-python-reference.py` | Small standalone Python script for creating, sending, and validating DD-UART frames |
| `dd-uart-frame-examples.md` | Extra frame examples and checksum calculations |
| `dd-uart-test-log.md` | Manual command test results |
| `stm32-command-map.md` | Firmware-side command dispatch map |
| `serial-debug-notes.md` | Debug notes for UART timeout, checksum, and parser issues |

## Documentation links

Related project documents:

```text
docs/03-software-architecture.md
docs/06-testing-and-tuning.md
docs/07-calibration-procedures.md
docs/10-risk-register.md
schemes/full-wiring-diagram.png
```

Example link from the root `README.md`:

```markdown
[DD-UART Protocol](other/protocol/dd-uart-protocol.md)
```

Example link from a file inside `docs/`:

```markdown
[DD-UART Protocol](../other/protocol/dd-uart-protocol.md)
```

## Update policy

When the protocol changes:

1. Update the STM32 firmware.
2. Update the Jetson Python command code.
3. Update `dd-uart-protocol.md`.
4. Update this README if new files are added.
5. Add or update command examples.
6. Run the manual command test checklist.
7. Commit the code and documentation together when possible.

## Current status

The folder currently documents the DD-UART protocol used by ARBIBOT for Jetson-to-STM32 communication. The active protocol uses binary frames with a start byte, total length, 16-bit command ID, optional payload, XOR checksum, and newline end byte.

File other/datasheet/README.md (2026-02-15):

# Datasheets – Hardware Component References

This folder contains official manufacturer datasheets and technical documentation for all major hardware components used in the Metallic-Madness WRO 2026 vehicle.

These documents were used during:

- Electrical design
- Firmware development
- Sensor integration
- Motor control calibration
- System architecture planning

---

## Components Included

### NVIDIA Jetson Orin Nano
High-performance SBC responsible for AI and decision-making.

File:
- Jetson-Orin-Nano-Series-Modules-Datasheet_DS-11105-001_v1.5.pdf

---

### STM32F411CE Microcontroller
Main real-time controller handling sensors and motor driver.

File:
- stm32f411ce.pdf

---

### Cytron MD10C Motor Driver
10A DC motor driver used for propulsion control.

File:
- cython Motor driver diagram MD10C datasheet.pdf

---

### 12V Double Shaft DC Gear Motor with Hall Encoder
Main drive motor with integrated encoder feedback.

File:
- Double Shaft DC Gear Motor Encoder 12V Hall.pdf

---

### VL53L7CH (8×8 Time-of-Flight Sensor)
Front multi-zone ranging sensor for obstacle perception.

File:
- vl53l7ch datasheet.pdf

---

### VL53L4CD (Single-Zone ToF Sensor)
Dual side distance sensors (Left and Right configuration).

File:
- vl53l4cd.pdf

---

### Pololu Maestro Servo Controller
Steering control module for precise servo positioning.

File:
- Pololu Maestro Servo Controller User guide.pdf

---

## Purpose of This Folder

These datasheets ensure:

- Correct voltage levels
- Safe operating conditions
- Accurate timing configuration
- Reliable communication setup
- Proper motor and encoder interfacing

All hardware integration decisions in this project are based on these official documents.

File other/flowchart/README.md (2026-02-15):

# Flowchart and Communication Protocol

This folder contains documentation describing the communication protocol used between:

- Jetson Orin Nano (High-Level Controller)
- STM32F411CE (Low-Level Real-Time Controller)

The communication is implemented over UART using a custom binary protocol called:

DD Protocol

---

## Protocol File

- UART Protocol with Length and Checksum.pdf

---

## Protocol Overview

The protocol ensures structured, reliable, and validated communication between the SBC and the microcontroller.

Frame structure:

| Field | Size | Description |
|---|---|---|
| Start Byte  | 1 byte | Frame identifier |
| Length | 2 bytes  | Total frame length |
| Command ID  | 2 bytes  | Action to execute |
| Data | N bytes  | Optional payload |
| Checksum | 1 byte | XOR validation |
| End Byte | 1 byte | Frame termination |

---

## Purpose of the Protocol

The protocol is designed to provide:

- Frame integrity verification
- Length validation
- Command structure consistency
- Error detection using XOR checksum
- Expandable command system

---

## System Communication Flow

1. Jetson processes camera input
2. AI decides vehicle action
3. Command is packed into DD Protocol frame
4. Frame is sent via UART
5. STM32 validates frame
6. STM32 executes command
7. STM32 optionally returns sensor data

This protocol guarantees deterministic control and prevents corrupted command execution during competition.

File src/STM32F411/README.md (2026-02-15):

# WRO 2026 – Future Engineers (STM32F411 Firmware)

Firmware for the WRO Future Engineers 2026 self-driving car platform (Metallic-Madness Team).  
The STM32F411 is the **low-level “vehicle controller”**: it drives the motor, reads sensors, and exchanges commands/telemetry with the main SBC (NVIDIA Jetson Orin Nano) over UART using the **DD Protocol**.

---

## What the STM32 Handles (Scope)

1. **Motor control** (MD10C driver)
   - PWM speed control
   - Direction control
   - Optional “move by degrees” using an encoder

2. **Sensors**
   - **VL53L7** (8×8 ToF grid) for front perception (distance/status matrix)
   - **VL53L4CD** (2× single-zone ToF) left/right ranging (dual sensors via XSHUT + address remap)
   - **IMU** (LSM6DS3TR-C) accel/gyro (currently present but reads are commented in `main.c`)

3. **Serial communication**
   - UART protocol parser in IRQ
   - Command execution in the main loop
   - Response messages sent back to the Jetson

---

## Firmware Architecture (High Level)

- **Interrupt context (UART RX)**:
  - Bytes are collected until an `END_BYTE` is detected.
  - The full message is validated (start byte, length, checksum, end byte).
  - A decoded command is stored in `received_message` and `new_message_ready` is raised.

- **Main loop**:
  - Watches `new_message_ready`
  - Executes the matching command (motor/sensors)
  - Sends back a response using the same DD Protocol framing

This keeps time-critical RX parsing in IRQ and leaves the heavy work (sensor reads, motor actions) in the main loop.

---

## Project Files (Reviewed)

### `main.c`
**Role:** Application entry point, peripheral init, sensor bring-up, command dispatcher.

Key responsibilities:
- Initializes HAL + clock + GPIO + I2C + UART + timers
- Starts:
  - Motor PWM (`motor_init`)
  - VL53L7 ranging (`sensor_vl53l7ch_init`, `sensor_vl53l7ch_start_ranging`)
  - Dual VL53L4CD sensors (XSHUT sequencing, I2C address remap, ranging start)
- Implements the **command switch-case** driven by `received_message.command`
- Provides `_write()` to redirect `printf()` to UART1 (useful for debugging)

Notes:
- IMU init and reads are present but commented out.
- Dual VL53L4CD setup uses XSHUT pins:
  - LEFT: `PA5`
  - RIGHT: `PA7`
- Dual VL53L4CD addresses are remapped to:
  - LEFT: `0x54`
  - RIGHT: `0x56`

---

### `motor_drv.c`
**Role:** Motor driver abstraction (MD10C control + encoder utilities).

What it provides:
- `motor_init()` ? binds timer/channel for PWM + direction GPIO, starts PWM
- `motor_set_speed(0..100)` ? PWM duty update
- `motor_forward(speed)` / `motor_reverse(speed)`
- `motor_forward_degrees(deg, speed)` / `motor_reverse_degrees(deg, speed)`
  - Converts degrees into encoder ticks (uses `PULSES_PER_REV`)
  - Busy-waits until the target ticks are reached, then stops
- `motor_encoder_update(chA, chB)` ? software quadrature decode into `encoder_count`
- `motor_get_rpm()` ? estimates RPM from delta encoder count over time

Important notes (worth fixing soon):
- `motor_get_rpm()` uses **PPR = 11** in the formula, while the file defines `PULSES_PER_REV = 1595`.
  - That mismatch will produce garbage RPM unless intentionally different sensors.
- The “degrees move” functions **busy-wait in a loop** with `printf()` inside.
  - Great for debugging, terrible for real-time behavior. Consider:
    - remove the prints
    - add a timeout
    - convert to non-blocking state machine

---

### `serial_dd_protocol.c`
**Role:** DD Protocol implementation: validate, decode, respond, and UART RX ISR.

Core pieces:
- `validate_message()`:
  - checks start/end bytes
  - checks embedded length matches received length
  - checksum = XOR of bytes `[1 .. length-3]`
- `process_message()`:
  - decodes into `DD_Uart_Message`
  - sets `received_message` + `new_message_ready`
- `send_response()` and `send_response_len()`:
  - build framed response messages using the same protocol
- `DD_USART1_IRQHandler()`:
  - reads bytes while RXNE flag set
  - accumulates until `END_BYTE`, then calls `process_message()`

Important notes:
- RX buffer is **100 bytes** in the IRQ handler.
  - But `send_response_len()` can transmit up to **1024 bytes**.
  - If the Jetson ever sends long frames, STM32 RX will truncate/break.
  - Recommendation: increase RX buffer and/or enforce max payload size in the protocol.

---

### `sensor_vl53l7ch.c`
**Role:** Wrapper around ST VL53L7CX ULD API (8×8 ranging).

What it does:
- Checks sensor alive (`vl53l7cx_is_alive`)
- Initializes (`vl53l7cx_init`)
- Configures:
  - autonomous mode
  - **8×8 resolution**
  - **10 Hz** ranging frequency
  - closest target order
  - prints current integration time
- Provides convenience wrappers:
  - start/stop ranging
  - check data ready
  - read results
  - debug print per-zone

---

### `sensor_vl53l4cd.c`
**Role:** Wrapper around ST VL53L4CD API (single sensor).

Provides:
- init + ID check
- start/stop ranging
- check ready
- get result
- clear interrupt
- debug print helper

Note:
- In `main.c`, the dual-sensor approach is implemented directly (XSHUT + address change),
  so this wrapper is currently more “single-sensor utility” than the main path.

---

### `platform2.c`
**Role:** ST “platform layer” for VL53L4CD API: I2C read/write primitives + delay.

Implements:
- `VL53L4CD_RdByte/RdWord/RdDWord`
- `VL53L4CD_WrByte/WrWord/WrDWord`
- `VL53L4CD_RdMulti`
- `VL53L4CD_WaitMs`

Uses:
- `hi2c2` (declared `extern`) as the I2C bus for VL53L4CD operations.

---

### `sensor_imu.c`
**Role:** IMU driver for LSM6DS3TR-C using I2C register reads/writes.

Provides:
- `sensor_imu_init()`:
  - checks `WHO_AM_I` (expects `0x6A`)
  - config accel + gyro
- `sensor_imu_read_accel()`
- `sensor_imu_read_gyro()`

Note:
- Calls are currently commented out in `main.c`, but the driver looks ready.

---

### `stm32f4xx_hal_msp.c`
**Role:** STM32CubeMX-generated MSP init for clocks/pins/peripheral low-level setup.

Highlights from the current config:
- **I2C1**
  - PB6 SCL, PB7 SDA (AF4)
- **I2C2**
  - PB10 SCL (AF4), PB9 SDA (AF9)
- **TIM3 PWM**
  - PA6 TIM3_CH1 (motor PWM)
- **TIM9 input capture pins**
  - PA2 TIM9_CH1, PA3 TIM9_CH2 (encoder inputs)
- **USART1**
  - PA9 TX, PA10 RX + IRQ enabled

---

### `stm32f4xx_it.c`
**Role:** Interrupt vector handlers.

Key customization:
- `USART1_IRQHandler()` calls `DD_USART1_IRQHandler()` instead of `HAL_UART_IRQHandler()`,
  so **your protocol RX runs directly in the interrupt**.

---

### `system_stm32f4xx.c`
**Role:** System startup / clock definitions (Cube-generated).

Typically contains:
- core clock config variables
- vector table relocation options
- `SystemInit()` / `SystemCoreClockUpdate()`

---

## DD Protocol (UART Frame Format)

Implemented in `serial_dd_protocol.c` (constants in `serial_dd_protocol.h`).

Frame layout:

| Field | Size | Notes |
|---|---|---|
| START | 1 byte | Must match `START_BYTE` |
| LENGTH | 2 bytes | Big-endian, **total frame length in bytes** |
| COMMAND | 2 bytes | Big-endian command ID |
| DATA | N bytes | `N = LENGTH - 7` |
| CHECKSUM | 1 byte | XOR of bytes `[1 .. LENGTH-3]` |
| END | 1 byte | Must match `END_BYTE` |

---

## Supported Commands (Current `main.c`)

> Command IDs shown in hex.

| Command | Meaning | Payload | Response |
|---|---|---|---|
| `0x0001` | Read gyro | (planned) | (currently commented) |
| `0x0002` | Read accel | (planned) | (currently commented) |
| `0x0003` | Read VL53L7 (8×8) | none | Returns formatted distances + statuses |
| `0x0004` | Motor forward | none | “Forward” |
| `0x0005` | Motor reverse | none | “Reverse” |
| `0x0101` | Forward by degrees | 2 bytes: `deg` (LE in current code) | “Moved Forward by degrees” |
| `0x0102` | Reverse by degrees | 2 bytes: `deg` (LE in current code) | “Moved Reverse by degrees” |
| `0x0103` | Stop motor | none | “Stopped” |
| `0x0104` | Set speed | 1 byte: `0..100` | “Speed updated” |
| `0x0105` | Read VL53L4CD L/R | none | “LEFT: X mm \| RIGHT: Y mm” |

?? Note on degrees payload:
- Code reads degrees as:  
  `deg = data[0] | (data[1] << 8)`  
  That is **little-endian**. Your frame’s command/length are big-endian, but degrees are currently treated as little-endian. Keep it consistent on the Jetson side (or adjust firmware).

---

## Build & Flash

Typical STM32CubeIDE flow:
1. Open the project in **STM32CubeIDE**
2. Build (Debug/Release)
3. Flash via ST-LINK

Serial debug:
- `printf()` is redirected to **USART1** via `_write()` in `main.c`.

---

## Practical TODOs (Recommended Next Fixes)

If you want this to behave like a race car and not like a debugging seminar:

1. **Make “move by degrees” non-blocking**
   - remove busy-wait loops
   - implement a motion state machine + periodic encoder checks

2. **Fix encoder constants**
   - unify `PULSES_PER_REV` vs RPM PPR constant

3. **RX buffer sizing**
   - increase RX buffer beyond 100 bytes or enforce a strict max payload size

4. **IMU enablement**
   - uncomment IMU init + reads and define response payload format

---

## Ownership / Credits

- Firmware: Metallic-Madness Team (WRO Future Engineers 2026)
- Sensor APIs: STMicroelectronics VL53 ULD/ULD API layers
- MCU HAL: STM32Cube HAL (ST)

---

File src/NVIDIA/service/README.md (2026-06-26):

# WRO 2026 Metallic Madness — `systemd` service

This folder contains the `systemd` unit that auto-starts `main.py` at boot on the
Jetson so the robot is ready for a WRO Open Challenge run without a console.

The unit is **safe by design**: at startup `main.py` initializes the hardware,
forces the motor into a **STOPPED / safe state**, centers the steering, and then
**waits for the physical Start button**. The vehicle does **not** move until the
button is pressed (after the judge says "Go").

- Unit file: [`wro-main.service`](wro-main.service)
- Service runs as user **`daniel`**
- Repo root (assumed): `/home/daniel/WRO2026-MetallicMadness`
- Python: `/usr/bin/python3`

> If your repository path or Python interpreter differ, edit `WorkingDirectory`,
> `ExecStart`, and the `StandardOutput`/`StandardError` paths in
> `wro-main.service` before installing.

---

## Competition startup behavior

```
Power switch ON
      │
      ▼
Jetson boots ──► systemd starts wro-main.service ──► runs main.py
      │
      ▼
Robot initializes (camera, sensors, serial/motor, servo)
      │
      ▼
Motors are explicitly STOPPED + steering centered  (safe state)
      │
      ▼
Robot WAITS for the Start button   ◄── no movement here
      │
   judge says "Go"  ──►  Start button PRESSED
      │
      ▼
Round starts ──► robot begins moving and runs the laps
```

`main.py` logs each of these lifecycle steps to both the console (→ `journalctl`)
and to a rotating file at `logs/main.log`.

---

## Install

```bash
# 0. From the repo root, make sure the logs folder exists (main.py also creates it)
cd /home/daniel/WRO2026-MetallicMadness
mkdir -p logs

# 1. Copy the unit file into systemd's directory
sudo cp service/wro-main.service /etc/systemd/system/wro-main.service

# 2. Reload systemd so it sees the new unit
sudo systemctl daemon-reload

# 3. Enable it to start automatically at every boot
sudo systemctl enable wro-main.service

# 4. Start it now (without rebooting)
sudo systemctl start wro-main.service
```

---

## Everyday commands

```bash
# Status (running? last exit? recent log lines)
sudo systemctl status wro-main.service

# Start / stop / restart
sudo systemctl start   wro-main.service
sudo systemctl stop    wro-main.service
sudo systemctl restart wro-main.service

# Enable (auto-start at boot) / disable (no auto-start)
sudo systemctl enable  wro-main.service
sudo systemctl disable wro-main.service
```

---

## Watching logs

```bash
# Live systemd journal for this service
journalctl -u wro-main.service -f

# This boot only, newest last
journalctl -u wro-main.service -b

# The application's own rotating log (lifecycle events, corner triggers, errors)
tail -f logs/main.log

# Raw stdout / stderr captured by the unit
tail -f logs/service.log
tail -f logs/service-error.log
```

> To see the high-frequency per-frame telemetry (`[WATCH]` / `[FRONT 4x4]`), run
> with `WRO_LOG_LEVEL=DEBUG`. For a manual run:
> `WRO_LOG_LEVEL=DEBUG python3 main.py`. For the service, add
> `Environment=WRO_LOG_LEVEL=DEBUG` to the unit and `daemon-reload` + `restart`.

---

## Test it manually (recommended before relying on the service)

```bash
cd /home/daniel/WRO2026-MetallicMadness

# Syntax check
python3 -m py_compile main.py

# Run by hand (Ctrl+C to stop). Motors stay stopped until the Start button.
python3 main.py
```

---

## Stop / restart during development

While testing, you usually want to stop the auto-started service (so it does not
fight your manual `python3 main.py` over the serial port), then re-enable it
before the competition.

```bash
# Stop the running service during testing
sudo systemctl stop wro-main.service

# Restart it (e.g. after editing code or pulling new files)
sudo systemctl restart wro-main.service

# Disable auto-start at boot while developing
sudo systemctl disable wro-main.service

# Re-enable auto-start (remember to do this before the competition)
sudo systemctl enable wro-main.service
```

---

## Disable auto-start / remove the service

```bash
# Stop it and prevent auto-start at boot
sudo systemctl stop wro-main.service
sudo systemctl disable wro-main.service

# Fully remove the unit
sudo rm /etc/systemd/system/wro-main.service
sudo systemctl daemon-reload
sudo systemctl reset-failed wro-main.service
```

---

## Serial / device permissions

The robot talks to the STM32 over a serial port (e.g. `/dev/ttyUSB0`) and the
servo over `/dev/ttyACM0`, uses the CSI camera, and reads a GPIO button. The
service runs as `daniel`, so that user needs access to those device groups.

```bash
# Check which serial devices exist and their group ownership
ls -l /dev/ttyUSB* /dev/ttyACM*

# Confirm daniel's current groups
groups daniel

# Add daniel to the useful hardware groups
sudo usermod -aG dialout daniel   # serial ports (/dev/ttyUSB*, /dev/ttyACM*)
sudo usermod -aG video   daniel   # camera
sudo usermod -aG gpio    daniel   # GPIO (start button)

# Group membership only takes effect after a fresh login session — reboot to be safe
sudo reboot
```

> If `main.py` fails to open the serial port with a *Permission denied* error,
> it is almost always missing `dialout` membership — re-check `groups daniel`
> after rebooting.

---

## Notes

- `Restart=on-failure` only relaunches on a **crash** (non-zero exit). A clean
  finish (laps completed) exits 0 and is **not** restarted — the car will not
  re-run itself on the track.
- `main.py` writes its own rotating log (`logs/main.log`, 5 MB × 5 backups) in
  addition to the raw `StandardOutput`/`StandardError` files configured here.

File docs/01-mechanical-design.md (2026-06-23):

# 01 - Mechanical Design

**Project:** MetallicMadness / ARBIBOT  
**Category:** WRO 2026 Future Engineers - Self-Driving Cars  
**Document purpose:** Explain the mechanical design of the vehicle, including chassis, dimensions, drive axle, steering linkage, motor selection, torque/speed reasoning, and design iterations.

> This document is part of the technical documentation package for the ARBIBOT self-driving car. It focuses only on the mechanical subsystem. Electronics, power, sensors, and software are documented in separate files.

---

## 1. Mechanical Design Goals

ARBIBOT was designed as a compact four-wheel autonomous vehicle for the WRO Future Engineers Self-Driving Cars challenge. The mechanical design had to satisfy several practical goals:

1. Stay inside the WRO size and weight limits.
2. Use a four-wheel vehicle layout with one driving axle and one steering actuator.
3. Provide enough torque to move the robot reliably with the Jetson, STM32, batteries, sensors, and wiring installed.
4. Maintain stable traction on the WRO track surface.
5. Allow accurate steering corrections during lane following, obstacle avoidance, and cornering.
6. Provide physical mounting positions for the Jetson Orin Nano, STM32F411, motor driver, sensors, batteries, camera, and wiring.
7. Keep the robot reproducible using 3D-printed components and commercially available electromechanical parts.

The final design uses a **3D-printed chassis**, **rear-wheel drive**, and **servo-actuated front-wheel steering**. The mechanical system was developed through several iterations, mainly around drive torque, wheel traction, sensor bumper placement, and steering geometry.

---

## 2. WRO Mechanical Compliance Summary

| Requirement / Parameter | ARBIBOT value | WRO limit / expectation | Status |
|---|---:|---:|---|
| Vehicle length | 250 mm | Max. 300 mm | OK |
| Vehicle width | 156 mm | Max. 200 mm | OK |
| Vehicle height | 180 mm | Max. 300 mm | OK |
| Vehicle weight | 1.35 kg | Max. 1.5 kg | OK |
| Wheel count | 4 wheels | 4-wheeled vehicle | OK |
| Drive configuration | Rear-wheel drive | Front, rear, or four-wheel drive allowed | OK |
| Steering actuator | 1 servo | One steering actuator allowed | OK |
| Differential drive | Not used | Differential wheeled base not allowed | OK |
| Omnidirectional / ball wheels | Not used | Not allowed | OK |
| Track width | 135 mm | Must remain within 200 mm total vehicle width | OK |
| Wheel diameter | Not recorded yet | Not specified by WRO | Optional measurement |

The robot remains below the maximum allowed envelope of **300 mm × 200 mm × 300 mm** and below the **1.5 kg** weight limit. The current mechanical margins are:

| Parameter | Margin |
|---|---:|
| Length margin | 50 mm |
| Width margin | 44 mm |
| Height margin | 120 mm |
| Weight margin | 0.15 kg |

These margins are important because the robot carries relatively heavy components, including the Jetson Orin Nano, the motor battery pack, the UPS module, the motor driver, and the 3D-printed sensor bumper.

---

## 3. Chassis Design

The chassis is based on a **custom 3D-printed structure**. The main reason for using a 3D-printed chassis was flexibility: the team needed to mount non-standard components such as the Jetson Orin Nano, STM32F411 Black Pill, Cytron MD10C motor driver, VL53 distance sensors, Pololu servo controller, camera module, battery system, and custom wiring.

The 3D-printed design allowed the team to quickly modify the structure during testing. This was important because several mechanical problems were discovered only after the robot was assembled and tested on the track. For example, the first bumper design rubbed against the tire during steering, and some distance sensors were initially mounted too low to measure the intended wall distance reliably. With a printed structure, the bumper and sensor mounts could be redesigned without rebuilding the entire vehicle.

ARBIBOT promotional photo

### 3.1 Main Chassis Functions

The chassis performs five mechanical functions:

1. **Structural support**  
   It holds the drive axle, steering system, electronics, batteries, sensors, and camera.

2. **Component positioning**  
   It places the camera and distance sensors where they can observe the track, walls, pillars, and front obstacles.

3. **Weight distribution**  
   It supports the heavier SBC and batteries while keeping the vehicle stable during acceleration and turning.

4. **Mechanical protection**  
   The bumper and printed frame protect the sensors and internal wiring from direct contact with obstacles or walls.

5. **Iteration support**  
   Because the frame is printed, the team can test, modify, and reprint mechanical parts as the design evolves.

### 3.2 Chassis Tradeoff

A 3D-printed chassis is easy to customize, but it can be less rigid than a metal or carbon fiber chassis. The team accepted this tradeoff because the WRO track is flat, the robot does not need suspension travel, and customization is more important than extreme stiffness. The printed structure also keeps the design reproducible for future teams.

The main design risk is that printed parts can flex or crack around screw holes, steering mounts, or bumper supports. For that reason, the team reinforced the steering and bumper areas and used screws for mechanical adjustment where alignment is critical.

---

## 4. Vehicle Dimensions and Layout

| Parameter | Value |
|---|---:|
| Length | 25.0 cm |
| Width | 15.6 cm |
| Height | 18.0 cm |
| Weight | 1.35 kg |
| Wheelbase | 13.9 cm |
| Track width | 13.5 cm, center-to-center between left and right wheels |
| Drive axle | Rear axle |
| Steering axle | Front axle |
| Chassis type | 3D printed |

The wheelbase of **13.9 cm** was selected to keep the vehicle short enough for the WRO starting zones while still providing enough stability for straight driving. A shorter wheelbase improves turning ability, but if it becomes too short the vehicle can become unstable and sensitive to steering changes. A longer wheelbase improves straight-line stability, but it can make cornering and parking more difficult.

The current wheelbase is a compromise between:

- cornering ability,
- lane stability,
- space for electronics,
- space for battery placement,
- mechanical room for the steering linkage,
- and WRO size constraints.

---

## 5. Drive Configuration

ARBIBOT uses **rear-wheel drive**. The rear axle is powered by a DC gear motor with encoder feedback. The front wheels are used for steering.

Rear-wheel drive was selected because it provides a simple and legal drivetrain layout for WRO. It avoids the prohibited differential-drive style where each side of the vehicle is driven independently. In ARBIBOT, steering is handled mechanically by the front steering linkage, and forward/reverse movement is handled by the rear drive system.

### 5.1 Why Rear-Wheel Drive Was Selected

Rear-wheel drive provides several advantages for this robot:

1. **Mechanical simplicity**  
   Only one main drive motor is required for propulsion.

2. **Compliance with WRO rules**  
   The robot uses a car-like layout instead of differential steering.

3. **Better separation of functions**  
   The rear axle handles propulsion while the front axle handles steering.

4. **Predictable control**  
   The Jetson and STM32 can control speed and steering as separate actions.

5. **Compatibility with encoder feedback**  
   The motor encoder can be used to estimate motor rotation, RPM, and movement by degrees.

### 5.2 Drive Axle Design

The drive axle is powered through the rear drivetrain. The motor is a **JGY-370B 12V worm gear motor with encoder**, selected for its low-speed torque and integrated feedback.

The previous drivetrain design used a single-shaft motor setup with a gearbox and connected rear wheels. During testing, this version had significant torque-transfer problems between the gearbox gear and the wheel gear. This made the robot unreliable under load. The final design moved toward a stronger motor/encoder configuration to improve movement consistency and control feedback.

---

## 6. Drive Motor

The drive motor is a **JGY-370B 12V Mini Worm Gear Motor with Encoder**, configured for approximately **150 RPM** no-load output speed.

| Motor parameter | Value |
|---|---|
| Motor type | DC worm gear motor with encoder |
| Model | JGY-370B |
| Rated voltage | 12 V DC |
| No-load speed | 150 RPM |
| Shaft type | D-type shaft |
| Gear material | Metal gears |
| Encoder type | Hall-effect quadrature encoder |
| Encoder phases | A/B square-wave output |
| Encoder base resolution | 11 PPR at motor shaft |
| Encoder voltage | 3.3 V / 5 V |
| Direction | CW / CCW reversible |

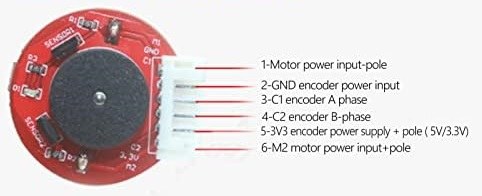
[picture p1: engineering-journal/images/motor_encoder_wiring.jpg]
Motor encoder wiring reference


### 6.1 Reason for Selecting a Worm Gear Motor

The worm gear motor was selected because the robot requires controlled low-speed movement more than high speed. WRO driving is not a drag race; the robot must complete laps autonomously, avoid walls, obey traffic signs, and park. A fast but unstable robot is just a very confident crash machine.

The worm gear motor provides:

- high torque at low speed,
- compact size,
- metal gearing,
- controlled motion,
- encoder feedback,
- and self-locking behavior when power is removed.

The self-locking characteristic is useful because the motor shaft resists unwanted movement when the motor is not powered. This can help the vehicle remain stable during stop conditions, although it also means the drivetrain may have more resistance than a free-spinning gear motor.

---

## 7. Speed Reasoning

The motor speed is **150 RPM** at the gearbox output under no-load conditions. The theoretical linear speed depends on the wheel diameter.

The estimated vehicle speed can be calculated using:

```text
wheel_circumference = pi × wheel_diameter

linear_speed = wheel_circumference × wheel_RPM / 60
```

Because the exact wheel diameter still needs to be measured, the final speed estimate is left as a calculation template:

```text
wheel_diameter = not recorded yet
wheel_RPM = 150 RPM no-load

linear_speed = pi × wheel_diameter × 150 / 60
```

Example table to complete after wheel diameter measurement:

| Wheel diameter | Estimated no-load speed |
|---:|---:|
| Not recorded yet | Not calculated because wheel diameter was not recorded |
| Not recorded yet | Not calculated because wheel diameter was not recorded |

The actual driving speed will be lower than the no-load calculation because the robot carries approximately **1.35 kg**, and because acceleration, steering friction, floor contact, battery voltage, and PWM speed limits reduce real movement speed.

### 7.1 Speed Tradeoff

The team selected a 150 RPM motor because it is slow enough to control accurately but fast enough to complete the track within the WRO time limit. A higher-RPM motor could reduce lap time, but it would increase overshoot, make corners harder to control, and reduce obstacle-avoidance stability. A lower-RPM motor would be easier to control but could make the robot too slow during the three-minute challenge window.

The selected motor is therefore a compromise between:

- speed,
- torque,
- steering stability,
- obstacle reaction time,
- and repeatability.

---

## 8. Torque Reasoning

Torque is important because ARBIBOT weighs approximately **1.35 kg** and must accelerate from rest, overcome rolling resistance, and continue moving while turning.

The motor supplier specification indicates a rated torque range depending on gearbox configuration, with a stall torque range higher than the rated torque. Because the exact gearbox torque table for the selected 150 RPM configuration must be confirmed, the team treats the published torque range as a reference and validates the drivetrain through physical testing.

The force available at the wheel can be estimated using:

```text
wheel_force = wheel_torque / wheel_radius
```

And wheel torque can be approximated from motor output torque:

```text
wheel_torque ≈ motor_output_torque × drivetrain_efficiency
```

To complete the final calculation, the following values should be measured or confirmed:

| Parameter | Value |
|---|---:|
| Motor output torque at 150 RPM | Not recorded from final supplier table; drivetrain validated through physical tests |
| Wheel radius | Not recorded yet |
| Drivetrain efficiency | Not recorded; worm gear losses expected |
| Estimated wheel force | Not calculated; practical torque validated by test driving |

### 8.1 Practical Torque Validation

During testing, the first drivetrain design had difficulty transferring torque reliably from the gearbox to the rear wheels. This was a real-world failure mode that mattered more than the theoretical motor rating. The issue showed that torque is not only about the motor; it is also about how torque is transferred through gears, shafts, couplers, and wheels.

The final design improved drivetrain reliability by using the selected JGY-370B motor with encoder feedback and a more controlled rear drive layout.

---

## 9. Encoder and Odometry Role

The drive motor includes a Hall-effect quadrature encoder. The encoder provides two output channels, phase A and phase B, which allow the STM32 to count pulses and determine rotation direction.

| Encoder parameter | Value |
|---|---|
| Encoder type | Hall-effect quadrature |
| Output phases | A and B |
| Base pulse count | 11 PPR |
| Output signal | Square wave |
| Voltage | 3.3 V / 5 V |
| Interface | PH 2.0 connector |
| MCU connection | STM32 GPIO / interrupt input |

The encoder is used for:

1. **Move-by-degrees commands**  
   The STM32 converts requested motor degrees into encoder counts.

2. **RPM estimation**  
   Encoder count change over time is used to estimate motor speed.

3. **Movement repeatability**  
   Encoder feedback helps make motor movements more consistent than timing-only control.

The encoder is not currently used as the primary corner-detection method. Corner timing is handled by camera and distance sensor logic, while turning behavior is mainly controlled by timed steering and motor commands.

---

## 10. Steering Mechanism

ARBIBOT uses a **servo-actuated pushrod steering mechanism with a tie-rod linkage between both front wheels**.

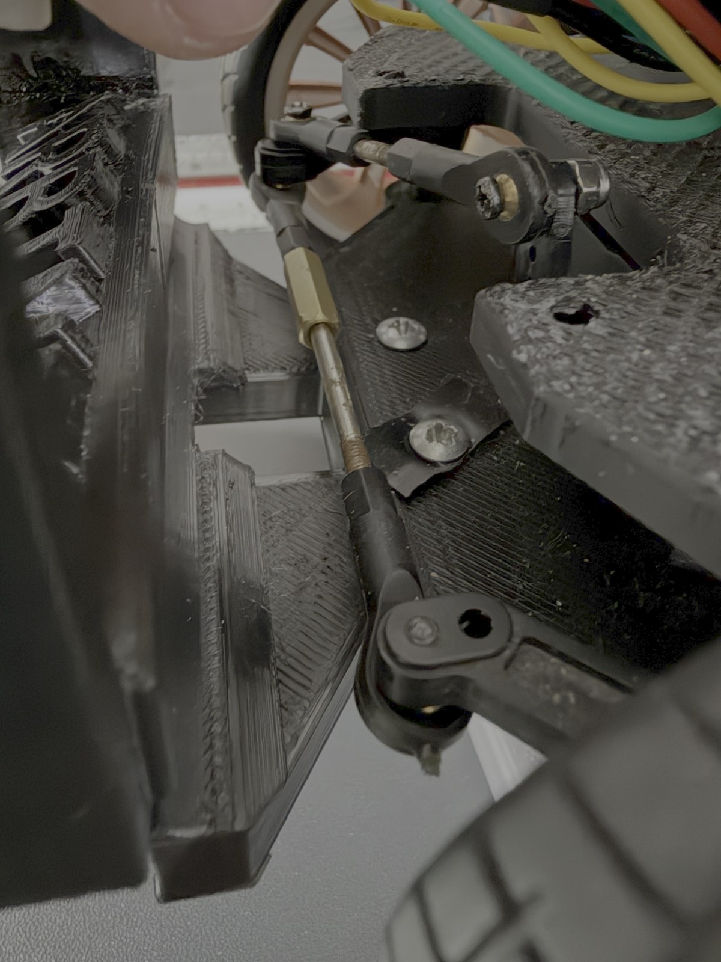
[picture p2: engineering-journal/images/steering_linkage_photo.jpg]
Steering linkage close-up


The steering servo moves a servo arm. The servo arm pushes and pulls a linkage connected to the right front steering knuckle. The left and right steering knuckles are connected by a tie rod, so both front wheels turn together.

The mechanism can be described as:

```text
servo → servo arm → pushrod → right steering knuckle → tie rod → left steering knuckle
```

This is a **custom pushrod/tie-rod front steering linkage**. It is Ackermann-inspired because the front wheels are connected mechanically through steering arms and a tie rod, but the team does not claim true Ackermann geometry until steering angles are measured and verified.

### 10.1 Steering Actuator

| Steering parameter | Value |
|---|---|
| Servo model | MG996R |
| Operating voltage | 5 V |
| Rated torque | 9.4 kg·cm at 4.8 V |
| Control method | Pololu servo controller |
| Steering type | Front-wheel steering |
| Linkage type | Pushrod + tie rod |

The MG996R servo was selected because it provides enough torque for the front steering system while remaining compact and easy to control. The servo does not directly rotate the wheels; it actuates the linkage, which transfers motion mechanically to both front wheels.

### 10.2 Servo Torque Conversion

The servo torque rating is given as **9.4 kg·cm**. This can be converted approximately to Newton-meters:

```text
1 kgf·cm ≈ 0.0981 N·m

9.4 kgf·cm × 0.0981 ≈ 0.92 N·m
```

This torque is adequate for steering a lightweight 1.35 kg robot on a flat WRO field, assuming the linkage has low friction and the wheels are not jammed against the wall or bumper.

### 10.3 Steering Linkage Tuning

During mechanical development, the team adjusted:

- the linkage rod lengths,
- the servo arm size,
- the pushrod connection point,
- and the front-wheel alignment screw.

These adjustments were necessary to achieve a usable turning range without excessive mechanical stress. The final steering alignment uses a screw adjustment to fine-tune the front-wheel angle.

The main steering design goals were:

1. enough steering angle to complete WRO corners,
2. stable straight-line movement,
3. minimal mechanical play,
4. no tire rubbing against the bumper,
5. and repeatable steering response from the servo.

### 10.4 Steering Tradeoff

A longer servo arm increases steering range but reduces effective force and can make steering more sensitive. A shorter servo arm increases force and precision but may not turn the wheels enough. The team adjusted the servo arm and linkage rods to find a usable compromise between turning radius and steering stability.

---

## 11. Wheel and Traction Design

The robot was tested with thinner wheels, but they slid on the track. This reduced reliability because the controller could command a turn, but the physical vehicle would not always follow the expected path.

The final design uses wider rubber tires with more contact area. This improved grip and made steering and acceleration more predictable.

### 11.1 Wheel Tradeoff

| Wheel option | Result |
|---|---|
| Thinner wheels | Lower contact area; slipped on the track |
| Wider rubber wheels | Better traction and more stable steering |
| Very soft tires | Not used in the final documented configuration |
| Very hard tires | Not used in the final documented configuration |

The selected wheels improve reliability, but they may increase rolling resistance. The team accepted this because reliable wall-following and obstacle avoidance are more important than maximum speed.

### 11.2 Remaining Wheel Measurements

The following values should be added after final measurement:

| Measurement | Value |
|---|---:|
| Wheel diameter | Not recorded yet |
| Wheel width | 2.5 cm |
| Track width | 13.5 cm |
| Minimum turning radius | Not recorded yet |
| Maximum left steering angle | Not recorded yet |
| Maximum right steering angle | Not recorded yet |

---

## 12. Sensor Bumper Mechanical Design

The front bumper holds the front distance sensors and helps protect them. The bumper went through several versions.

The first bumper design rubbed against the tire when the wheels turned. This created mechanical interference and affected steering reliability. The team redesigned the bumper and repositioned the sensors so that the tires could turn freely.

The sensors were also originally mounted too low. This caused unreliable distance readings because the sensors were not always measuring the intended wall or obstacle surface. The team repositioned the sensors to improve the measurement angle and distance reliability.

### 12.1 Bumper Design Goals

The bumper must:

1. hold the front VL53L8CH sensor,
2. hold the left and front-right VL53L4CD sensors,
3. avoid rubbing against the front tires,
4. keep sensors aligned with the expected wall/obstacle height,
5. protect wiring,
6. and remain inside the WRO vehicle size limit.

### 12.2 Sensor-Mount Tradeoff

Low-mounted sensors can detect close obstacles but may read the floor, bumper edges, or wheel shadows. Higher sensors may be cleaner but can miss low objects or change the measured geometry. The final sensor height was selected based on test readings at fixed distances.

---

## 13. Design Iterations

The mechanical design evolved through testing. The main iterations are summarized below.

| Area | Initial approach | Problem found | Final improvement |
|---|---|---|---|
| Drive motor | Motor without encoder | No direct feedback for movement control | Encoder motor selected |
| Rear drivetrain | Single-shaft motor with gearbox and connected rear wheels | Torque-transfer issues between gearbox gear and wheel gear | Stronger rear-drive configuration with encoder feedback |
| Wheels | Thinner wheels | Slid on the track | Wider tires with better traction |
| Distance sensing | Ultrasonic sensors | Lower precision and less reliable readings | VL53 laser time-of-flight sensors |
| Front bumper | First printed bumper | Rubbed against tire during turns | Bumper redesigned and sensor position adjusted |
| Sensor height | Sensors mounted too low | Distance readings were less reliable | Sensors repositioned to better measure walls/obstacles |
| Steering linkage | Early linkage geometry | Turning range and alignment needed tuning | Rod lengths, servo arm size, and alignment screw adjusted |

These iterations show that the final robot was not only assembled; it was improved through repeated testing and design correction.

---

## 14. Mechanical Failure Modes and Mitigation

| Failure mode | Cause | Mitigation |
|---|---|---|
| Tire rubbing against bumper | Bumper too close to steering path | Redesign bumper clearance |
| Wheel slip | Thin wheels / low traction | Use wider rubber tires |
| Poor torque transfer | Gearbox-to-wheel coupling issue | Change motor/drivetrain configuration |
| Steering not centered | Linkage length and servo neutral offset | Use mechanical adjustment screw and servo calibration |
| Excessive steering sensitivity | Servo arm too long or linkage geometry too aggressive | Adjust servo arm and linkage rod length |
| Sensor reading instability | Sensors too low or poorly aligned | Reposition sensor mounts |
| Chassis flex | 3D-printed structure under load | Reinforce mounting points and reduce unsupported spans |
| High center of gravity | Jetson and electronics mounted above chassis | Keep batteries and heavier components low where possible |

---

## 15. Reproducibility Notes

To reproduce the mechanical design, another team should prepare:

1. 3D-printed chassis and bumper parts.
2. Four wheels with sufficient grip for the WRO mat.
3. JGY-370B 12V 150 RPM worm gear motor with encoder.
4. MG996R steering servo.
5. Pushrod and tie-rod linkage hardware.
6. Mounting screws, nuts, spacers, and alignment hardware.
7. Sensor brackets for VL53L4CD and VL53L8CH sensors.
8. Electronics mounting points for Jetson, STM32, motor driver, servo controller, batteries, and wiring.

Recommended CAD files to include in the repository:

```text
models/cad/chassis.step
models/cad/front-bumper.stl
models/cad/sensor-mount-left-vl53l4cd.stl
models/cad/sensor-mount-right-vl53l4cd.stl
models/cad/front-vl53l8ch-mount.stl
models/cad/jetson-mount.stl
models/cad/stm32-mount.stl
models/cad/battery-holder.stl
models/drawings/vehicle-top-dimensions.pdf
models/drawings/vehicle-side-dimensions.pdf
```

---

## 16. Pending Measurements

The following values should be measured and added before final submission:

| Pending item | Reason |
|---|---|
| Track width | Required for a complete dimensioned mechanical description |
| Wheel diameter | Needed for speed calculation |
| Wheel width | Helps explain traction choice |
| Minimum turning radius | Important for cornering and parking explanation |
| Maximum steering angle left/right | Shows steering capability |
| Actual loaded speed at 50%, 75%, 100% PWM | Validates speed reasoning |
| Motor current under load | Connects mechanical load to power budget |
| Drive axle connection photo | Improves reproducibility |
| Full top-view steering photo with arrows | Makes linkage easier for judges to understand |

---

## 17. Conclusion

The mechanical design of ARBIBOT uses a compact 3D-printed chassis, rear-wheel drive, a 12V worm gear motor with encoder feedback, and a servo-actuated pushrod/tie-rod front steering system. The final design was selected after testing several alternatives, including a motor without encoder, thinner wheels, ultrasonic sensors, early bumper layouts, and different steering linkage settings.

The strongest mechanical decisions were:

- using a 3D-printed structure for fast iteration,
- selecting rear-wheel drive for WRO compliance and control simplicity,
- using a worm gear motor for torque and controlled low-speed motion,
- adding encoder feedback for repeatable movement,
- using wider wheels to improve traction,
- and tuning the steering linkage mechanically to improve turning range and alignment.

The remaining work is to complete exact measurements for wheel diameter, track width, turning radius, and steering angle. Once these values are added, this document will provide a strong and reproducible mechanical design explanation for WRO evaluation.

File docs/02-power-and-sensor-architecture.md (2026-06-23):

# 02 - Power and Sensor Architecture

**Project:** MetallicMadness / ARBIBOT  
**Category:** WRO 2026 Future Engineers - Self-Driving Cars  
**Document purpose:** Explain the electrical power architecture, battery systems, regulators, current draw, wiring organization, sensor placement, I2C design, and calibration process.

> This document is part of the ARBIBOT technical documentation package. It focuses on the power and sensor subsystem. Mechanical design and software architecture are documented separately.

---

## 1. Design Goals

The power and sensor architecture of ARBIBOT was designed around one main principle: **separate noisy high-current loads from sensitive logic and sensing electronics**.

ARBIBOT uses two main electronic domains:

1. **Low-level control domain**  
   This includes the STM32F411, distance sensors, motor driver interface, encoder feedback, and sensor acquisition.

2. **High-level AI and vision domain**  
   This includes the NVIDIA Jetson Orin Nano, CSI camera, YOLO inference, navigation decisions, and steering servo controller.

The vehicle uses independent power paths for the motor system and the Jetson system. This reduces the probability that motor current spikes will reset the Jetson, disturb sensor readings, or corrupt UART communication. Motors are electrically noisy little gremlins; the design keeps them away from the parts that need clean signals.

---

## 2. High-Level Electrical Architecture

ARBIBOT uses a distributed architecture:

```text
NVIDIA Jetson Orin Nano
    |
    | USB / UART serial command link
    v
STM32F411 Black Pill
    |
    | PWM + direction
    v
Cytron MD10C Motor Driver
    |
    v
12V DC Gear Motor with Encoder

STM32F411
    |
    | I2C bus + XSHUT address control
    v
VL53L4CD and VL53L8CX Distance Sensors

Jetson Orin Nano
    |
    | CSI camera
    v
IMX477 Camera

Jetson / Pololu
    |
    | Servo signal
    v
MG996R Steering Servo
```

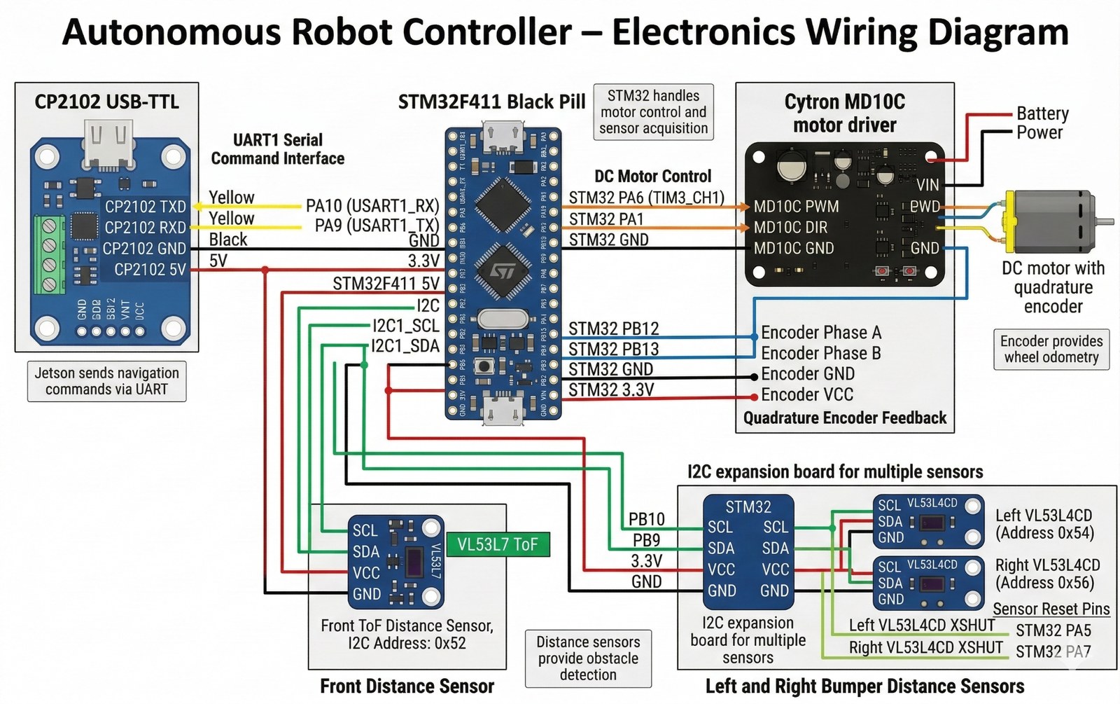
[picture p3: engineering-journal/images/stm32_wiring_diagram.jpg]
STM32 wiring diagram


The STM32 handles real-time hardware interaction, while the Jetson handles the computationally expensive tasks such as image capture, YOLO inference, object classification, and navigation decision logic.

---

## 3. Power Architecture Overview

ARBIBOT uses **two independent 3S battery systems**. This is one of the most important reliability decisions in the robot.

| System | Battery | Main loads | Purpose |
|---|---|---|---|
| System A — Logic and steering | Waveshare UPS, 3 × 18650 cells, 11.1 V nominal / 12.6 V full | Jetson, camera path, STM32 subtree, servo, I²C board, VL53 sensors | AI, vision, steering, sensors, high-level and low-level control |
| System B — Drive | Separate 3S 18650 motor battery, 11.1 V nominal / 12.6 V full | 3S 20A BMS, Cytron MD10C, 12V JGY-370B motor | Rear-wheel propulsion |

The power paths are separated to improve reliability. The DC drive motor and steering servo can draw high peak current during acceleration, hard turning, or stall conditions. If the Jetson, camera, sensors, servo, and motor were powered from one weak shared supply, a current spike could cause voltage sag, camera dropout, UART errors, or a Jetson reboot.

The final architecture keeps the high-current drive path separate from the logic/vision path:

```text
System A:
Waveshare UPS -> Jetson / steering servo / I²C sensor rail

System B:
3S motor battery -> 3S 20A BMS -> Cytron MD10C -> 12V JGY-370B motor
```

---

## 4. Drive Motor Power Path

The drive motor is powered through a **separate 3S motor battery**, a **3S 20A BMS**, and a **Cytron MD10C motor driver**.

```text
3S 18650 Li-ion motor battery
    |
    v
3S 20A BMS
    |
    v
Cytron MD10C motor driver
    |
    v
JGY-370B 12V DC worm gear motor with encoder
```

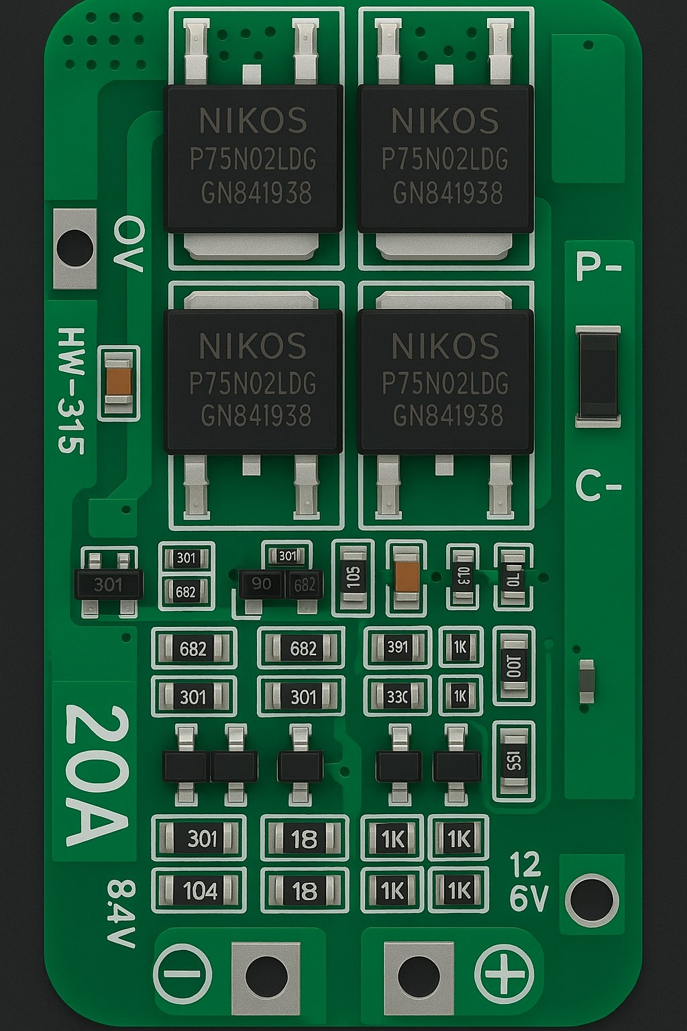
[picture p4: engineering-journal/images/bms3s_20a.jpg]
BMS 3S 20A


### 4.1 Motor Battery

| Parameter | Value |
|---|---|
| Cell type | 18650 lithium-ion |
| Cell nominal voltage | 3.7 V |
| Cell capacity | 1200 mAh |
| Series configuration | 3S |
| Pack nominal voltage | 11.1 V |
| Pack fully charged voltage | 12.6 V |
| Approximate pack capacity | 1200 mAh, because cells are connected in series |
| Approximate energy | 11.1 V × 1.2 Ah = 13.32 Wh |
| Protection | 3S 20A BMS |
| Main load | Cytron MD10C + 12V JGY-370B drive motor |

The nominal motor pack voltage is close to the 12V requirement of the selected DC gear motor. The BMS protects the lithium-ion cells and provides the motor power path to the motor driver.

### 4.2 Cytron MD10C Motor Driver

The robot uses a **Cytron MD10C DC motor driver** to control the brushed DC gear motor.

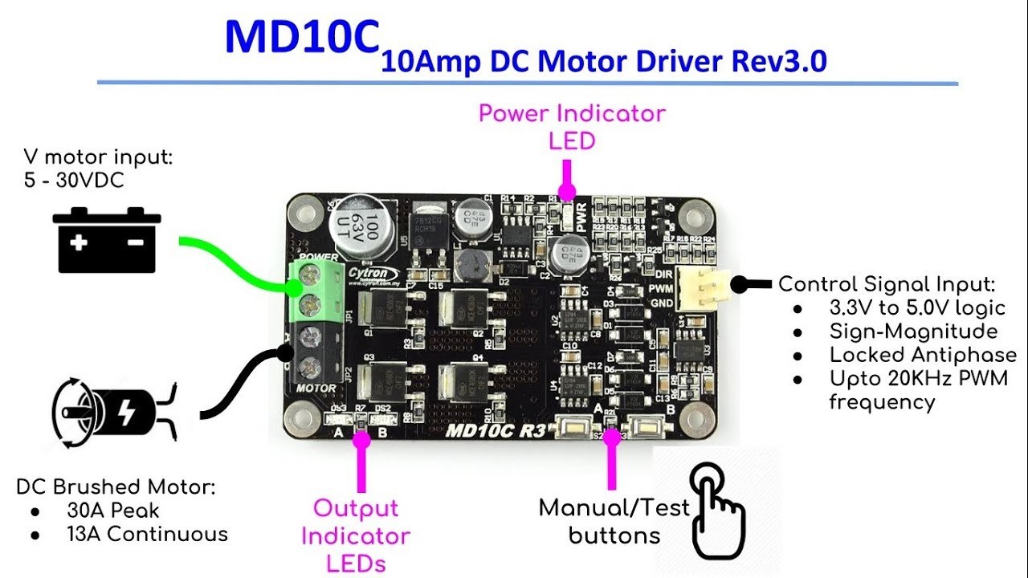
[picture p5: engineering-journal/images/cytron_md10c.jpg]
Cytron MD10C motor driver


| MD10C parameter | Value |
|---|---|
| Motor voltage input | 5 V to 30 V DC |
| Control logic | 3.3 V to 5.0 V compatible |
| Control mode | PWM + direction |
| PWM frequency | Up to 20 kHz |
| Rated continuous current | 13 A |
| Peak current | 30 A |
| STM32 PWM pin | PA6 / TIM3_CH1 |
| STM32 direction pin | PA1 |
| Common ground | Required between STM32 and MD10C control reference |

The STM32 sends a PWM signal and direction signal to the MD10C. The MD10C then switches the motor power from the battery/BMS path.

### 4.3 Motor Current and Power Estimate

The JGY-370B motor current depends heavily on load. The expected values are:

| Motor condition | Estimated current | Estimated power from 3S pack |
|---|---:|---:|
| No-load | 0.06 A to 0.09 A | ~0.7 W to 1.0 W |
| Normal driving load | 0.2 A to 0.3 A | ~2.2 W to 3.3 W |
| Average motor runtime estimate | ~0.6 A | ~6.7 W |
| Stall / peak condition | 1.3 A to 2.0 A | ~14 W to 22 W |

The motor stall estimate is far below the 20 A BMS rating and far below the MD10C rating. The practical motor-side risks are not energy capacity; they are voltage sag under load, wiring quality, connector reliability, and avoiding wheel stall.

---

## 5. Logic and Steering Power Path

The Jetson, steering servo, I²C expansion board, and distance sensors are powered independently from the drive motor system using a **Waveshare UPS module**.

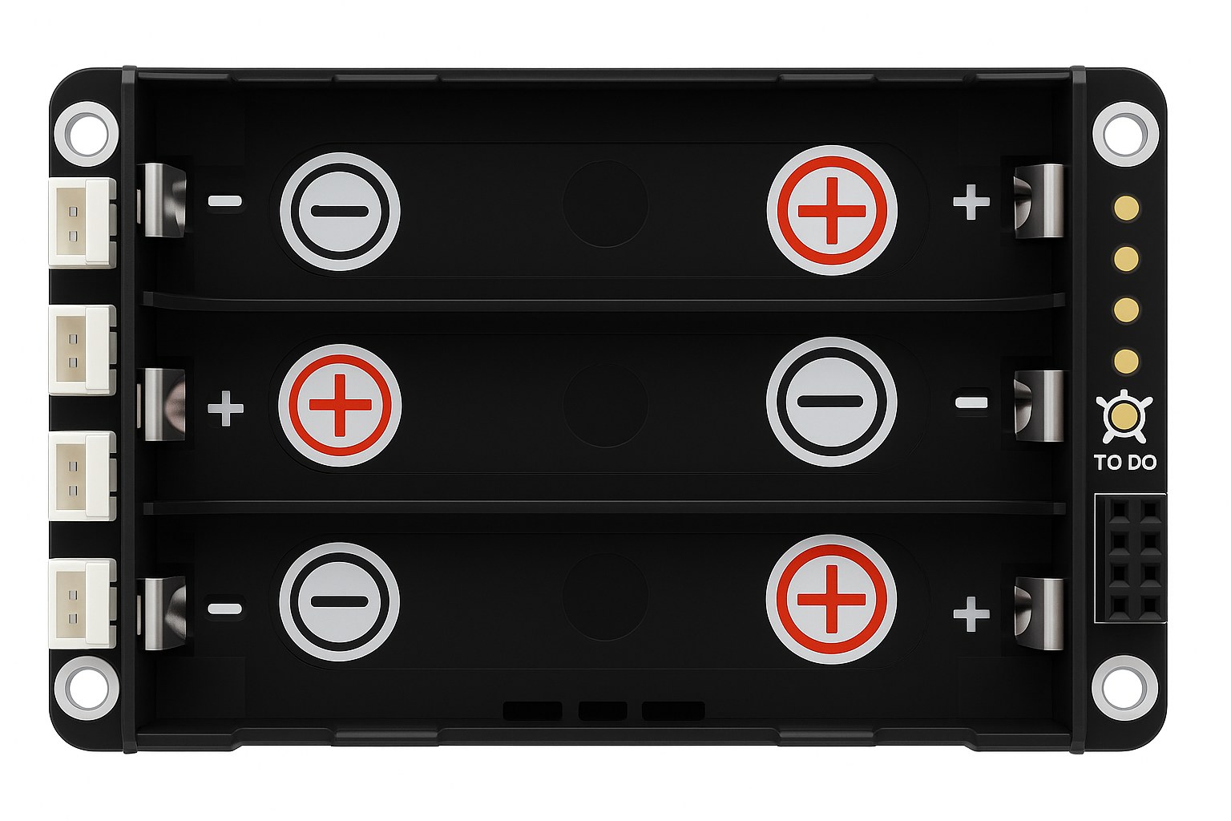
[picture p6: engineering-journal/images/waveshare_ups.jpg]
Waveshare UPS module


| UPS parameter | Value |
|---|---|
| Battery support | 3 × 18650 lithium batteries |
| Pack nominal voltage | 11.1 V |
| Pack fully charged voltage | 12.6 V |
| Pack capacity | 1200 mAh |
| Approximate energy | 13.32 Wh |
| Output voltage | Battery series voltage / 12V path; 5 V 5 A; 3.3 V 300 mA |
| Control interface | I²C |
| Charger | 12.6 V 2 A |
| Dimensions | 60 × 93 mm |
| Mounting hole size | 3.0 mm |
| Jetson supply voltage used | 12 V / battery series voltage path |

The Jetson system was separated from the motor battery because the Jetson is sensitive to voltage drops. When YOLO11n inference is running, the Jetson can draw significant power. Sharing the same supply with the drive motor could cause resets or unstable behavior.

### 5.1 Logic and Steering Power Distribution

```text
Waveshare UPS
    |
    +--> 12 V -> NVIDIA Jetson Orin Nano
    |
    +--> 5 V -> MG996R steering servo
    |
    +--> 5 V -> I²C expansion board -> 3× VL53L4CD + VL53L8CX
```

The Jetson internally powers the IMX477 camera, CP2102 USB-TTL module, and STM32F411 subtree through its USB/CSI-related rails. These devices are listed separately for traceability, but their power draw is already included in the Jetson workload estimate.

### 5.2 Jetson Current and Power Estimate

| Jetson condition | Estimated current / power |
|---|---:|
| Typical AI/vision workload | ~2.3 A at 11.1 V / ~25 W |
| Peak workload | ~40 W |
| Notes | Includes camera path, USB devices, and active vision workload as part of Jetson domain |

The Jetson runs YOLO11n, OpenCV camera capture, navigation logic, and serial communication. The nano model was selected partly to keep inference latency low and avoid starving the serial sensor/control loop.

### 5.3 Camera, STM32, and USB Subtree

These devices are traceable loads, but they are not added separately to the UPS total because they draw from the Jetson rails.

| Component | Source | Current | Power | Notes |
|---|---|---:|---:|---|
| IMX477 camera | Jetson MIPI CSI | ~180 mA | ~0.60 W | Included in Jetson domain |
| CP2102 USB-TTL | Jetson USB | ~20 mA | ~0.07 W | Included in Jetson USB load |
| STM32F411 | CP2102 3.3 V path / Jetson USB subtree | ~40 mA | ~0.13 W | 100 MHz estimate |

---

## 6. Sensor and I²C Power Path

The I²C expansion board and VL53 sensors are powered from the UPS 5V rail.

| Component | Source / rail | Current | Power |
|---|---|---:|---:|
| VL53L4CD ×3 | UPS 5 V through I²C board | ~60 mA total | ~0.30 W |
| VL53L8CX | UPS 5 V through I²C board | ~60 mA typical, ~120 mA peak | ~0.30 W typical |
| I²C expansion board | UPS 5 V | ~10 mA to 20 mA | ~0.08 W |

The sensors communicate with the STM32 over I²C. Their power path is part of the logic/sensor domain, not the motor domain.

---

## 7. Servo Power and Steering Control

The robot uses an **MG996R servo** for steering. The steering signal is managed by a Pololu servo controller.

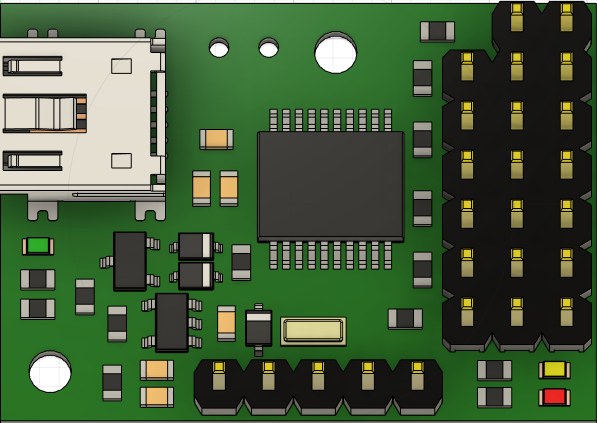
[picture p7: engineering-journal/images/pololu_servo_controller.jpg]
Pololu servo controller


| Steering power/control parameter | Value |
|---|---|
| Steering servo | MG996R |
| Servo voltage | 5 V |
| Rated torque | 9.4 kg·cm at 4.8 V |
| Control board | Pololu servo controller |
| Servo power source | Waveshare UPS 5 V rail |
| Steering mechanism | Servo-actuated pushrod and tie-rod linkage |

### 7.1 Servo Current and Power Estimate

| Servo condition | Estimated current | Estimated power at 5 V |
|---|---:|---:|
| Idle | ~10 mA | ~0.05 W |
| No-load movement | 120 mA to 170 mA | ~0.6 W to 0.85 W |
| Normal steering load | 0.5 A to 0.9 A | ~2.5 W to 4.5 W |
| Stall / peak | Up to 2.5 A | ~12.5 W |

The servo can draw high peak current when the front wheels are under load or when the steering linkage is blocked. The linkage must be mechanically smooth, and the steering software should avoid commanding against mechanical limits.

---

## 8. Power Budget and Runtime

The following table summarizes the traced component power budget.

### 8.1 Component Power Table

| Component | Source / rail | Current | Power | Value type |
|---|---|---:|---:|---|
| NVIDIA Jetson Orin Nano | UPS 12 V | 2.3 A typical at 11.1 V | 25 W typical, 40 W peak | Spec / workload |
| MG996R servo | UPS 5 V | 0.5–0.9 A running, 2.5 A stall | 2.5–4.5 W running, ~12.5 W stall | Datasheet |
| VL53L4CD ×3 | UPS 5 V through I²C board | ~60 mA total | ~0.30 W | Datasheet |
| VL53L8CX | UPS 5 V through I²C board | ~60 mA typical, peak ~120 mA | ~0.30 W typical | Datasheet |
| I²C expansion board | UPS 5 V | ~10–20 mA | ~0.08 W | Estimate |
| STM32F411 | CP2102 3.3 V from Jetson USB | ~40 mA | ~0.13 W | Datasheet, 100 MHz |
| IMX477 camera | Jetson MIPI CSI | ~180 mA | ~0.60 W | Spec |
| CP2102 USB-TTL | Jetson USB | ~20 mA | ~0.07 W | Datasheet |
| JGY-370B drive motor | 3S motor battery through MD10C | 0.2–0.3 A running, 1.3–2.0 A stall | ~2.2–3.3 W running, ~14–22 W stall | Datasheet / estimate |

### 8.2 Double-Counting Note

The IMX477, CP2102, and STM32F411 draw from the Jetson USB/CSI-related rails. They are listed for traceability, but their power is already inside the Jetson 25 W typical workload estimate.

### 8.3 UPS 5 V Rail Check

The UPS 5 V rail is rated for approximately:

```text
5 V × 5 A = 25 W
```

Expected 5 V peak load:

```text
MG996R servo stall: approximately 2.5 A
Sensors + I²C board: approximately 0.14 A
Total 5 V peak: approximately 2.6 A
```

This is within the 5 A UPS 5 V rail rating.

### 8.4 UPS Peak-Current Sag Check

The worst-case UPS pack draw happens if the Jetson reaches a peak workload while the steering servo is near stall:

```text
Jetson peak: approximately 40 W
Servo stall reflected to battery side: approximately 1.3 A equivalent
Estimated UPS pack peak draw: approximately 4.5 A to 5 A
```

This is approximately a 4C peak draw for 1200 mAh cells. This is the main remaining power risk because it may cause voltage sag if the cells cannot supply the peak current comfortably.

### 8.5 Runtime Estimate

| Runtime parameter | Value |
|---|---:|
| UPS average load | ~29 W |
| UPS energy | ~13.3 Wh |
| UPS runtime at 85% efficiency | ~24 min |
| Motor battery energy | ~13.3 Wh |
| Motor runtime estimate at ~0.6 A average | ~2 hr motor-time |
| WRO round duration | 3 min |
| UPS margin | ~8× one round |
| Motor battery margin | ~40× one round |

The runtime calculation shows that both battery systems have enough energy margin for a 3-minute WRO round.

### 8.6 Remaining Power Verification Item

The only open power item is empirical verification of peak-current sag during simultaneous Jetson high load and steering servo high load.

Test condition:

```text
YOLO11n running
camera active
serial polling active
servo performing aggressive steering
robot driving on the mat
```

Watch for:

```text
Jetson reboot
camera dropout
USB serial disconnect
STM32 reset
servo glitch
YOLO process interruption
```

If voltage sag is observed, recommended improvements are:

```text
use higher-discharge 18650 cells
add a 1000 µF or larger capacitor across the servo 5 V rail
check connector resistance and wire gauge
```

### 8.7 Power Measurement Plan

Before final submission, the team should verify:

| Test case | Measurement needed |
|---|---|
| Robot idle, powered on | Baseline current |
| YOLO11n inference active | Jetson workload stability |
| Servo aggressive left/right steering | 5 V rail stability |
| Motor forward continuous | Drive current |
| Motor acceleration from stop | Motor peak current |
| All sensors ranging | Sensor rail stability |
| Full 3-minute run | Real competition runtime and voltage drop |
| Battery voltage before/after 3 minutes | Remaining margin |
| Aggressive steering + YOLO active | Confirm no UPS voltage sag/reboot |

These measurements support the WRO documentation criterion for power reasoning and close the remaining power-risk item.

---

## 9. Grounding and Noise Considerations

All control signals require a common reference. The STM32, MD10C, encoder, sensors, and serial interface must share the proper ground reference for communication and control signals.

Important grounding rules:

1. The STM32 GND must connect to the MD10C GND.
2. The motor battery negative and logic ground must be referenced correctly where required by the driver/control signal path.
3. Encoder GND must connect to STM32 GND.
4. Sensor GND must connect to STM32 GND.
5. UART GND must connect between Jetson/USB-TTL and STM32.
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

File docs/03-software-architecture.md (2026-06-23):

# 03 - Software Architecture

**Project:** MetallicMadness / ARBIBOT  
**Category:** WRO 2026 Future Engineers - Self-Driving Cars  
**Document purpose:** Explain the software architecture of ARBIBOT, including the Jetson/STM32 split, main modules, state machine, command flow, DD-UART protocol, sensor/motor coordination, and challenge behavior.

> This document is part of the ARBIBOT technical documentation package. It focuses on software structure and system behavior. Mechanical design, power, and sensor hardware are documented separately.

---
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

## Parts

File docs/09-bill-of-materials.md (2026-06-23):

# 09 - Bill of Materials

**Project:** MetallicMadness / ARBIBOT  
**Category:** WRO 2026 Future Engineers - Self-Driving Cars  
**Document purpose:** Document the main components used in ARBIBOT, including component function, voltage, estimated current, communication interface, and subsystem role.

> This Bill of Materials is written for engineering documentation and reproducibility. Current values are based on the current ARBIBOT design notes and should be verified against final datasheets and measured current values before final submission.

---

## 1. Purpose of the Bill of Materials

This document lists the main mechanical, electrical, electronic, sensor, compute, and power components used in ARBIBOT.

The goal is to make the robot easier to:

- understand,
- reproduce,
- debug,
- evaluate,
- repair,
- and improve.

The Bill of Materials also helps explain why each component exists in the system and how it connects to the rest of the robot.

---

## 2. System Overview

ARBIBOT is divided into the following hardware subsystems:

| Subsystem | Main components |
|---|---|
| Compute and vision | NVIDIA Jetson Orin Nano, IMX477 camera |
| Low-level control | STM32F411 Black Pill |
| Motor drive | Cytron MD10C, JGY-370B motor, encoder |
| Steering | MG996R servo, Pololu servo controller |
| Distance sensing | VL53L4CD sensors, VL53L8CX front matrix sensor |
| Power | 3S 18650 motor battery, 3S BMS, Waveshare UPS module |
| Communication | CP2102 USB-TTL, USB serial links, I2C bus |
| Mechanical | 3D-printed chassis, wheels, steering linkage, bumper |

---

## 3. Main Component Summary

| # | Component | Qty | Function | Voltage | Current / power | Interface |
|---:|---|---:|---|---|---|---|
| 1 | NVIDIA Jetson Orin Nano | 1 | AI compute, camera processing, YOLO11n inference, navigation decisions | 12V input from Waveshare UPS path | 25W typical, 40W peak | USB, CSI camera, serial |
| 2 | IMX477 camera | 1 | Vision input for pillars, lines, and corner features | Powered from Jetson MIPI CSI | ~180mA / ~0.60W, included in Jetson domain | MIPI CSI-2 |
| 3 | STM32F411CEU6 Black Pill | 1 | Low-level control, sensor polling, motor control, encoder reading | 3.3V from CP2102 / Jetson USB subtree | ~40mA / ~0.13W | USB/UART, I2C, GPIO, PWM, EXTI |
| 4 | Cytron MD10C motor driver | 1 | Drives rear DC gear motor | 3S motor battery, 11.1V nominal / 12.6V full | Motor dependent; driver rated 13A continuous / 30A peak | PWM + DIR from STM32 |
| 5 | JGY-370B 12V worm gear motor with encoder | 1 | Rear-wheel drive motor | 12V nominal from 3S motor path | 0.2-0.3A run, 1.3-2.0A stall | DC motor wires + quadrature encoder |
| 6 | MG996R servo | 1 | Front steering actuator | 5V from Waveshare UPS | 0.5-0.9A run, 2.5A stall | Servo PWM via Pololu controller |
| 7 | Pololu Micro Maestro servo controller | 1 | Dedicated servo pulse controller | 5V logic / servo power input depending wiring | Controller low; servo current handled by servo power path | USB serial / TTL serial, servo PWM |
| 8 | VL53L4CD ToF distance sensor | 3 | Side/front distance sensing and wall following | 5V module rail through I²C board / 3.3V logic internally | ~60mA total / ~0.30W | I2C + XSHUT |
| 9 | VL53L8CX front matrix ToF sensor | 1 | Front barrier and corner matrix sensing | 5V module rail through I²C board / 3.3V logic internally | ~60mA typical, ~120mA peak / ~0.30W typical | I2C + optional XSHUT |
| 10 | CP2102 USB to TTL module | 1 | USB serial bridge for STM32 / debugging | Powered from Jetson USB | ~20mA / ~0.07W, included in Jetson domain | USB, UART TX/RX |
| 11 | Waveshare UPS module | 1 | Power supply for logic and steering domain | 3 × 18650, 11.1V nominal / 12.6V full | UPS 5V rail rated 5A / 25W | Power + optional I2C |
| 12 | 3S 18650 motor battery pack | 1 | Main drive motor power source | 11.1V nominal, 12.6V full | 1200mAh / ~13.3Wh | Power |
| 13 | 3S 20A BMS | 1 | Motor battery protection | 3S Li-ion, 12.6V full | 20A module rating | Power |
| 14 | I2C interface expansion board | 1 | Cleaner I2C and power wiring for sensors | 5V sensor rail | ~10-20mA / ~0.08W | I2C bus |
| 15 | 3D-printed chassis | 1 | Mechanical structure | N/A | N/A | Mechanical |
| 16 | Front bumper / sensor mount | 1 | Holds front/side sensors and protects front | N/A | N/A | Mechanical |
| 17 | Rubber wheels | 4 | Contact with WRO field | N/A | N/A | Mechanical |
| 18 | Steering linkage / tie rod / pushrod | 1 set | Transfers servo motion to front wheels | N/A | N/A | Mechanical |
| 19 | Wires, connectors, screws, spacers | As needed | Electrical and mechanical assembly | Depends | Depends | Power, signal, mechanical |

---

## 4. Detailed Component Records

---

## 4.1 NVIDIA Jetson Orin Nano

| Field | Value |
|---|---|
| Component | NVIDIA Jetson Orin Nano |
| Quantity | 1 |
| Subsystem | Compute and vision |
| Function | Runs camera capture, YOLO inference, image processing, challenge strategy, high-level navigation, and serial command output |
| Input voltage | 12V power path through robot UPS/power system |
| Estimated power | Up to ~25W typical workload, up to ~40W high load estimate |
| Interface | MIPI CSI-2 camera, USB serial, USB peripherals, network/SSH for development |
| Connected to | Camera, STM32 serial link, servo controller if USB-connected, Jetson UPS |
| Main software | Python, OpenCV, Ultralytics YOLO, challenge scripts |
| Documentation links | `docs/03-software-architecture.md`, `docs/02-power-and-sensor-architecture.md` |

### Reason for use

The Jetson was selected because ARBIBOT uses AI-based vision. YOLO inference and camera processing require more compute power than a small microcontroller can provide.

### Risk notes

| Risk | Mitigation |
|---|---|
| High power draw | Use dedicated UPS/power path |
| Camera or YOLO process failure | Test camera before each run |
| Blocking serial communication slows vision | Use non-blocking motor command strategy |
| Thermal or power instability | Verify runtime under full load |

---

## 4.2 IMX477 Camera

| Field | Value |
|---|---|
| Component | IMX477 camera |
| Quantity | 1 |
| Subsystem | Vision |
| Function | Provides front visual input for pillar detection, line/corner detection, and navigation |
| Voltage | Powered directly from Jetson camera interface |
| Current | ~180 mA / ~0.60 W, included in Jetson domain |
| Interface | MIPI CSI-2, 22-pin 0.5mm pitch cable |
| Connected to | NVIDIA Jetson Orin Nano |
| Used by | YOLO models, OpenCV frame processing |
| Documentation links | `docs/07-calibration-procedures.md`, `docs/03-software-architecture.md` |

### Reason for use

The camera gives semantic information that distance sensors cannot provide, especially pillar color and visual corner/line information.

### Calibration notes

- Camera angle must be fixed before YOLO confidence and zone calibration.
- Lens should be cleaned before testing.
- Lighting and glare should be tested before competition.

---

## 4.3 STM32F411CEU6 Black Pill

| Field | Value |
|---|---|
| Component | STM32F411CEU6 Black Pill |
| Quantity | 1 |
| Subsystem | Low-level embedded control |
| Function | Reads sensors, manages I2C, controls motor driver, reads encoder, handles UART protocol |
| Input voltage | 5V from USB/TTL power path |
| Logic voltage | 3.3V |
| Estimated current | ~40 mA / ~0.13 W estimate at 100 MHz |
| Interface | USB/UART, I2C, GPIO, PWM, EXTI |
| Connected to | VL53 sensors, MD10C motor driver, motor encoder, Jetson serial link |
| Firmware role | Command parser, sensor acquisition, motor control, response frames |
| Documentation links | `docs/03-software-architecture.md`, `docs/02-power-and-sensor-architecture.md` |

### Reason for use

The STM32 handles low-level real-time tasks more deterministically than Linux on the Jetson. It is responsible for sensor timing, motor PWM, encoder interrupts, and command execution.

### Important pins and signals

| Signal | Purpose | Notes |
|---|---|---|
| I2C SCL/SDA | VL53 distance sensors | Shared bus |
| XSHUT PA5 | Left VL53L4CD | Used for address initialization |
| XSHUT PA7 | Right-front VL53L4CD | Used for address initialization |
| XSHUT PB14 | Right-rear VL53L4CD | Used for address initialization |
| PWM output | MD10C speed control | Exact pin in firmware |
| DIR output | MD10C direction control | Exact pin in firmware |
| Encoder A/B inputs | Motor encoder feedback | EXTI / interrupt input |
| UART/USB | Jetson communication | DD-UART protocol |

---

## 4.4 Cytron MD10C Motor Driver

| Field | Value |
|---|---|
| Component | Cytron MD10C |
| Quantity | 1 |
| Subsystem | Motor drive |
| Function | Drives the rear DC gear motor using PWM and direction control |
| Input voltage | Motor battery path, nominal 11.1V / full 12.6V |
| Current | Must handle motor load and stall current; verify final margin |
| Interface | PWM + DIR from STM32 |
| Connected to | 3S BMS, motor, STM32 |
| Documentation links | `schemes/full-wiring-diagram.png`, `docs/02-power-and-sensor-architecture.md` |

### Reason for use

The MD10C is a robust motor driver module suitable for controlling the rear DC gear motor. It separates low-power STM32 logic from the high-current motor path.

### Risk notes

| Risk | Mitigation |
|---|---|
| Incorrect motor direction | Verify FORWARD/REVERSE before field run |
| Motor noise affects logic | Use separated power paths and careful wiring |
| Motor stall | Avoid blocked wheels and excessive load |

---

## 4.5 JGY-370B 12V Worm Gear Motor with Encoder

| Field | Value |
|---|---|
| Component | JGY-370B 12V mini worm gear motor with encoder |
| Quantity | 1 |
| Subsystem | Drivetrain |
| Function | Rear-wheel drive motor |
| Voltage | 12V nominal |
| Speed | Approximately 150 RPM model |
| Estimated current | 0.06-0.09A no-load, 0.2-0.3A rated load, 1.3-2.0A stall estimate |
| Interface | DC motor power wires + quadrature encoder |
| Connected to | MD10C motor output, STM32 encoder inputs |
| Documentation links | `docs/01-mechanical-design.md`, `docs/07-calibration-procedures.md` |

### Wiring reference

| Wire color | Function |
|---|---|
| Red | Motor DC power positive |
| White | Motor DC power negative |
| Blue | Encoder V+ |
| Black | Encoder GND |
| Yellow | Encoder signal A or B |
| Green | Encoder signal B or A |

### Reason for use

This motor provides a balance of torque, manageable speed, metal gearing, encoder feedback, and compact size.

### Calibration needed

| Calibration | Purpose |
|---|---|
| Motor direction | Confirm FORWARD and REVERSE |
| Minimum moving speed | Find lowest reliable movement speed |
| Safe competition speed | Balance lap time and control |
| Encoder ticks per wheel revolution | Support movement feedback |

---

## 4.6 MG996R Steering Servo

| Field | Value |
|---|---|
| Component | MG996R servo |
| Quantity | 1 |
| Subsystem | Steering |
| Function | Actuates front steering linkage |
| Voltage | 5V |
| Torque | 9.4 kg·cm at 4.8V stated in project notes |
| Estimated current | ~10mA idle, 120-170mA no-load, 500-900mA normal load, 1.5-2.5A stall |
| Interface | PWM servo pulse |
| Connected to | Pololu servo controller, steering linkage |
| Documentation links | `docs/01-mechanical-design.md`, `docs/07-calibration-procedures.md` |

### Reason for use

The MG996R provides enough torque for the front steering mechanism and is commonly available.

### Calibration needed

| Calibration | Purpose |
|---|---|
| Servo center | Straight front wheels |
| Left limit | Avoid linkage binding |
| Right limit | Avoid tire/bumper interference |
| Steering clamp | Prevent aggressive obstacle steering |

---

## 4.7 Pololu Micro Maestro Servo Controller

| Field | Value |
|---|---|
| Component | Pololu Micro Maestro servo controller |
| Quantity | 1 |
| Subsystem | Steering control |
| Function | Generates stable servo PWM signals |
| Voltage | 5V logic / servo power input depending wiring |
| Current | Controller current low; servo current passes through servo power path |
| Interface | USB serial or TTL serial |
| Connected to | Jetson or control computer, MG996R servo |
| Documentation links | `schemes/full-wiring-diagram.png`, `docs/03-software-architecture.md` |

### Reason for use

A dedicated servo controller reduces timing complexity and provides reliable steering pulse output.

### Risk notes

| Risk | Mitigation |
|---|---|
| USB port changes | Verify port before run |
| Servo power dip | Ensure adequate servo power |
| Wrong servo channel | Label and document final channel |

---

## 4.8 VL53L4CD Distance Sensors

| Field | Value |
|---|---|
| Component | VL53L4CD ToF distance sensor |
| Quantity | 3 |
| Subsystem | Distance sensing |
| Function | Side/front distance sensing, wall following, heading correction |
| Voltage | 3.3V logic/module dependent |
| Estimated current | ~15-25mA active per sensor |
| Interface | I2C + XSHUT |
| Connected to | STM32F411 |
| Documentation links | `docs/02-power-and-sensor-architecture.md`, `docs/07-calibration-procedures.md` |

### Placement

| Sensor | Position | Function | Address | XSHUT |
|---|---|---|---:|---|
| Left VL53L4CD | Front/left bumper area | Left/front distance sensing | `0x52` | PA5 |
| Right-front VL53L4CD | Front/right bumper area | Right wall distance | `0x54` | PA7 |
| Right-rear VL53L4CD | Middle/right side between wheels | Right heading correction | `0x56` | PB14 |

> Address map confirmed against the current firmware mapping.

### Reason for use

VL53L4CD sensors provide more precise short-range distance measurements than ultrasonic sensors for the compact WRO field geometry.

---

## 4.9 VL53L8CX / VL53L7CX-Style Front Matrix Sensor

| Field | Value |
|---|---|
| Component | VL53L8CX front matrix ToF sensor |
| Quantity | 1 |
| Subsystem | Front distance sensing |
| Function | Front matrix distance sensing for front wall, obstacles, and corner trigger support |
| Voltage | 3.3V logic/module dependent |
| Current | ~60 mA typical, ~120 mA peak; ~0.30 W typical |
| Interface | I2C |
| Connected to | STM32F411 |
| Documentation links | `docs/02-power-and-sensor-architecture.md`, `docs/07-calibration-procedures.md` |

### Reason for use

The front matrix sensor provides multiple distance zones instead of a single front value. This helps detect front barriers and avoid false corner triggers when filtered correctly.

### Calibration needed

| Parameter | Purpose |
|---|---|
| Matrix row used | Select useful cells |
| Valid distance band | Reject floor/invalid values |
| Required valid cells | Prevent one-cell false trigger |
| Trigger distance | Decide when to turn |

---

## 4.10 CP2102 USB to TTL Serial Module

| Field | Value |
|---|---|
| Component | CP2102 USB 2.0 to TTL module |
| Quantity | 1 |
| Subsystem | Communication / debugging |
| Function | USB-to-serial bridge for STM32 communication or testing |
| Voltage | USB 5V input, TTL output depending module configuration |
| Current | ~20 mA / ~0.07 W, included in Jetson USB domain |
| Interface | USB, UART TX/RX |
| Connected to | Development computer, STM32, or Jetson depending test setup |
| Documentation links | `schemes/full-wiring-diagram.png`, `docs/03-software-architecture.md` |

### Reason for use

The CP2102 module provides a practical way to test UART communication and interact with STM32 serial commands during development.

---

## 4.11 Waveshare UPS Module

| Field | Value |
|---|---|
| Component | Waveshare UPS module |
| Quantity | 1 |
| Subsystem | Power |
| Function | Provides power for Jetson/electronics domain |
| Battery input | 3 x 18650 cells |
| Charging input | 12.6V / 2A charger according to project notes |
| Outputs | 5V 5A, 3.3V 300mA, and battery/12V path depending module configuration |
| Interface | Power + optional I2C monitoring |
| Connected to | Jetson Orin Nano, servo controller/power distribution depending final wiring |
| Documentation links | `docs/02-power-and-sensor-architecture.md`, `schemes/power-distribution-diagram.png` |

### Reason for use

The UPS module gives the Jetson and electronics a more stable power path separated from motor current spikes.

### Risk notes

| Risk | Mitigation |
|---|---|
| Insufficient output current | Test full load with YOLO, camera, servo, and sensors |
| Low battery | Measure voltage before run |
| Connector movement | Secure power cables |

---

## 4.12 3S 18650 Motor Battery Pack

| Field | Value |
|---|---|
| Component | 3S 18650 lithium-ion battery pack |
| Quantity | 1 |
| Subsystem | Motor power |
| Function | Supplies motor power through BMS and motor driver |
| Nominal voltage | 11.1V |
| Full voltage | 12.6V |
| Capacity | 1200mAh cells mentioned in project notes; final pack capacity should be verified |
| Current | Depends on cell capability and motor load |
| Interface | Power |
| Connected to | 3S 20A BMS |
| Documentation links | `docs/02-power-and-sensor-architecture.md` |

### Reason for use

A 3S pack provides voltage suitable for the 12V gear motor and motor driver path.

---

## 4.13 3S 20A BMS

| Field | Value |
|---|---|
| Component | 3S 20A BMS |
| Quantity | 1 |
| Subsystem | Motor battery protection |
| Function | Protects the 3S Li-ion motor battery pack |
| Voltage | 3S Li-ion, 12.6V full |
| Current rating | 20A module rating |
| Interface | Power |
| Connected to | Motor battery, Cytron MD10C |
| Documentation links | `schemes/power-distribution-diagram.png` |

### Reason for use

The BMS protects the motor battery pack from unsafe charge/discharge conditions and provides a controlled motor power path.

---

## 4.14 I2C Interface Expansion Board

| Field | Value |
|---|---|
| Component | I2C interface expansion board |
| Quantity | 1 |
| Subsystem | Sensor wiring |
| Function | Organizes I2C and power wiring for sensors |
| Voltage | 3.3V / 5V depending final wiring |
| Current | Low current; sensor dependent |
| Interface | I2C bus |
| Connected to | STM32 and VL53 sensors |
| Documentation links | `docs/02-power-and-sensor-architecture.md`, `schemes/full-wiring-diagram.png` |

### Reason for use

The I2C expansion board helps keep wiring cleaner and makes sensor connections easier to manage.

> Note: This board is used as a wiring/interface expansion board, not as an intelligent I2C multiplexer unless final hardware proves otherwise.

---

## 4.15 3D-Printed Chassis

| Field | Value |
|---|---|
| Component | Custom 3D-printed chassis |
| Quantity | 1 |
| Subsystem | Mechanical |
| Function | Main robot structure |
| Voltage | N/A |
| Current | N/A |
| Interface | Mechanical mounting |
| Connected to | All mechanical and electronic subsystems |
| Documentation links | `docs/01-mechanical-design.md`, `v-photos/` |

### Known dimensions

| Measurement | Value |
|---|---:|
| Length | 25 cm |
| Width | 16.0 cm outside wheel-to-wheel / 15.6 cm chassis reference |
| Height | 18 cm |
| Weight | 1.35 kg |
| Wheelbase | 13.9 cm |
| Track width | 13.5 cm center-to-center |

### Reason for use

3D printing allowed custom mounting for sensors, electronics, steering, bumper geometry, and rapid mechanical iteration.

---

## 4.16 Front Bumper and Sensor Mount

| Field | Value |
|---|---|
| Component | Front bumper / sensor mount |
| Quantity | 1 |
| Subsystem | Mechanical / sensors |
| Function | Holds front and side sensors and protects front area |
| Voltage | N/A |
| Current | N/A |
| Interface | Mechanical |
| Connected to | Chassis, VL53 sensors |
| Documentation links | `v-photos/front-bumper.png`, `schemes/sensor-placement-diagram.png` |

### Reason for use

The front bumper gives a defined location for the front distance sensor and the left/right sensors. It also protects the front of the robot.

### Iteration notes

Earlier bumper versions caused tire rubbing and poor sensor placement. The bumper was redesigned to improve clearance and sensor alignment.

---

## 4.17 Wheels

| Field | Value |
|---|---|
| Component | Rubber wheels |
| Quantity | 4 |
| Subsystem | Mechanical drivetrain |
| Function | Provide contact with WRO field and support car-like movement |
| Voltage | N/A |
| Current | N/A |
| Interface | Mechanical |
| Connected to | Rear drive axle, front steering hubs |
| Documentation links | `docs/01-mechanical-design.md` |

### Reason for use

Wider rubber wheels were selected after thinner wheels slipped on the track. Better traction improved repeatability.

---

## 4.18 Steering Linkage

| Field | Value |
|---|---|
| Component | Pushrod/tie-rod steering linkage |
| Quantity | 1 set |
| Subsystem | Mechanical steering |
| Function | Transfers servo motion to front wheels |
| Voltage | N/A |
| Current | N/A |
| Interface | Mechanical |
| Connected to | MG996R servo, front steering hubs |
| Documentation links | `docs/01-mechanical-design.md`, `v-photos/` |

### Reason for use

The linkage creates a simple car-like steering mechanism and allows mechanical adjustment of wheel alignment.

---

## 4.19 Wires, Connectors, Screws, Spacers, Cable Management

| Field | Value |
|---|---|
| Component | Wiring and hardware accessories |
| Quantity | As needed |
| Subsystem | Electrical and mechanical integration |
| Function | Power, signal, mounting, strain relief |
| Voltage | Depends on circuit |
| Current | Depends on circuit |
| Interface | Power, UART, I2C, GPIO, mechanical |
| Connected to | All subsystems |

### Notes

Important wiring practices:

- keep motor wires away from sensitive I2C/UART lines where possible,
- secure wires so they cannot touch wheels,
- keep grounds connected where needed for signal reference,
- label sensor and motor wires,
- use strain relief for moving sections,
- verify connectors after crashes.

---

## 5. Power Domain Summary

ARBIBOT uses two independent 3S battery systems.

### 5.1 System A — Logic and Steering Domain

```text
Waveshare UPS, 3 × 18650 cells
11.1V nominal / 12.6V full / ~13.3Wh
    |
    +--> 12V path -> NVIDIA Jetson Orin Nano
    |
    +--> 5V rail -> MG996R steering servo
    |
    +--> 5V rail -> I²C expansion board -> 3× VL53L4CD + VL53L8CX
```

| Component | Voltage / source | Current / power notes |
|---|---|---|
| Waveshare UPS | 3 × 18650, 11.1V nominal / 12.6V full | ~13.3Wh energy |
| Jetson Orin Nano | UPS 12V path | 25W typical, 40W peak |
| MG996R servo | UPS 5V rail | 0.5-0.9A run, 2.5A stall |
| VL53L4CD ×3 | UPS 5V through I²C board | ~60mA total / ~0.30W |
| VL53L8CX | UPS 5V through I²C board | ~60mA typical, ~120mA peak |
| I²C expansion board | UPS 5V | ~10-20mA / ~0.08W |
| IMX477 camera | Jetson MIPI CSI | ~180mA / ~0.60W, included in Jetson domain |
| CP2102 USB-TTL | Jetson USB | ~20mA / ~0.07W, included in Jetson domain |
| STM32F411 | CP2102 / Jetson USB subtree | ~40mA / ~0.13W |

### 5.2 System B — Drive Motor Domain

```text
3S 18650 motor battery
11.1V nominal / 12.6V full / ~13.3Wh
    |
    v
3S 20A BMS
    |
    v
Cytron MD10C
    |
    v
12V JGY-370B drive motor
```

| Component | Voltage / source | Current / power notes |
|---|---|---|
| 3S motor battery | 11.1V nominal / 12.6V full | 1200mAh / ~13.3Wh |
| 3S BMS | 3S Li-ion | 20A module rating |
| Cytron MD10C | 3S motor battery path | 13A continuous / 30A peak driver rating |
| JGY-370B motor | 12V nominal | 0.2-0.3A run, 1.3-2.0A stall |

### 5.3 Runtime and Rail Margin

| Metric | Value |
|---|---:|
| UPS average load | ~29W |
| UPS energy | ~13.3Wh |
| UPS runtime at 85% efficiency | ~24 min |
| Motor battery energy | ~13.3Wh |
| Motor runtime estimate at ~0.6A average | ~2 hr motor-time |
| WRO round length | 3 min |
| UPS margin | ~8× one round |
| Motor battery margin | ~40× one round |

### 5.4 Remaining Power Verification

The power budget closes the energy and rail-rating questions, but one empirical item remains:

```text
Test simultaneous YOLO11n high load + aggressive steering servo load.
```

Watch for Jetson reboot, camera dropout, USB serial disconnect, STM32 reset, or servo glitch. If voltage sag appears, use higher-discharge 18650 cells and add a 1000µF or larger capacitor across the servo 5V rail.

---

## 6. Communication and Interface Summary

| Link | From | To | Interface | Purpose |
|---|---|---|---|---|
| Camera link | IMX477 camera | Jetson | MIPI CSI-2 | Vision frames |
| Main command link | Jetson | STM32 | USB serial / UART | Motor/sensor commands |
| Servo link | Jetson or controller host | Pololu Micro Maestro | USB serial / TTL serial | Steering commands |
| Sensor bus | STM32 | VL53 sensors | I2C | Distance readings |
| XSHUT lines | STM32 | VL53L4CD sensors | GPIO | Address initialization |
| Motor control | STM32 | MD10C | PWM + DIR | Speed and direction |
| Encoder feedback | Motor encoder | STM32 | Quadrature A/B | Wheel feedback |
| Power path | Battery/BMS/UPS | Subsystems | Power wiring | Energy distribution |

---

## 7. Estimated Current Budget

These values are traced estimates based on the current ARBIBOT power architecture.

| Subsystem | Quantity | Typical current / power | Peak current / power | Notes |
|---|---:|---:|---:|---|
| Jetson Orin Nano | 1 | 25W typical | 40W peak | Includes vision workload and Jetson-powered subtree |
| IMX477 camera | 1 | ~180mA / ~0.60W | Not recorded yet | Powered from Jetson; listed for traceability |
| STM32F411 | 1 | ~40mA / ~0.13W | Not recorded yet | Powered through CP2102 / Jetson USB subtree |
| MG996R servo | 1 | 0.5-0.9A / 2.5-4.5W | 2.5A / ~12.5W stall | Main 5V peak-current risk |
| JGY-370B motor | 1 | 0.2-0.3A / ~2.2-3.3W | 1.3-2.0A / ~14-22W stall | Separate 3S motor battery path |
| VL53L4CD | 3 | ~60mA total / ~0.30W | Not recorded yet | Sensor rail |
| VL53L8CX | 1 | ~60mA / ~0.30W | ~120mA peak | Sensor rail |
| I²C expansion board | 1 | ~10-20mA / ~0.08W | Low | Wiring/interface board |
| CP2102 | 1 | ~20mA / ~0.07W | Not recorded yet | Jetson USB subtree |

---

## 8. Component Selection Reasoning

| Component choice | Reason |
|---|---|
| Jetson Orin Nano | Needed for real-time camera processing and YOLO inference |
| STM32F411 | Reliable low-level control, I2C, PWM, encoder interrupts |
| VL53 ToF sensors | More precise than ultrasonic sensors for compact WRO geometry |
| VL53L8CX front matrix | Provides multi-zone front distance information |
| JGY-370B worm gear motor | Good torque, manageable speed, encoder feedback |
| MG996R servo | Enough torque for steering linkage |
| Cytron MD10C | Robust motor driver for DC gear motor |
| Pololu controller | Stable servo pulse generation |
| Separate power domains | Reduces motor noise and voltage-drop problems |
| 3D-printed chassis | Allows rapid iteration and custom mounts |

---

## 9. Alternatives Rejected

| Component / approach | Reason rejected |
|---|---|
| Ultrasonic sensors | Less precise and less suitable for near-wall WRO geometry |
| Motor without encoder | No reliable feedback for movement validation |
| Thin wheels | Slipped on the field |
| Shared power path for everything | Higher risk of Jetson brownout and sensor instability |
| Camera-only navigation | Too dependent on lighting and visual features |
| Single side distance sensor | Could not estimate robot heading relative to wall |
| Direct Jetson low-level motor control | Less deterministic than STM32 for embedded control |
| L298N-style motor driver | Lower efficiency and not preferred for motor current path |

---

## 10. Spare Parts Recommended

Recommended spare parts for testing and competition:

| Spare part | Reason |
|---|---|
| Extra 18650 cells | Battery replacement and runtime reliability |
| Extra VL53L4CD sensor | Sensor damage or address/debug replacement |
| Extra servo horn | Steering linkage repairs |
| Extra MG996R servo | Servo gear or motor failure |
| Extra CP2102 module | Serial debugging backup |
| Extra wires/connectors | Field repairs |
| Extra screws/nuts/spacers | Mechanical repairs |
| Extra wheels | Traction or damage replacement |
| Extra 3D-printed bumper | Crash replacement |
| Extra camera cable | CSI cable damage replacement |

---

## 11. Final BOM Table for Competition

Complete measured values can be added after multimeter/current testing. The current traced values are shown below.

| Item | Qty final | Verified voltage | Current / power | Verified interface | Final status |
|---|---:|---:|---:|---|---|
| Jetson Orin Nano | 1 | UPS 12V path | 25W typical, 40W peak | CSI, USB, serial | Verified estimate |
| IMX477 camera | 1 | Jetson CSI | ~180mA / ~0.60W | MIPI CSI-2 | Verified estimate, included in Jetson domain |
| STM32F411 | 1 | 3.3V logic from CP2102 / USB subtree | ~40mA / ~0.13W | UART, I2C, PWM, GPIO | Verified estimate |
| Cytron MD10C | 1 | 3S motor battery, 11.1V / 12.6V | Motor dependent; driver 13A continuous / 30A peak | PWM + DIR | Verified architecture |
| JGY-370B motor | 1 | 12V nominal from 3S motor path | 0.2-0.3A run, 1.3-2.0A stall | DC motor + encoder | Verified estimate |
| MG996R servo | 1 | UPS 5V | 0.5-0.9A run, 2.5A stall | PWM via Pololu | Verified estimate |
| Pololu servo controller | 1 | 5V | Low controller current, servo load separate | USB serial / TTL serial | Verified architecture |
| VL53L4CD | 3 | 5V module rail through I²C board | ~60mA total / ~0.30W | I2C + XSHUT | Verified estimate |
| VL53L8CX | 1 | 5V module rail through I²C board | ~60mA typical, ~120mA peak | I2C | Verified estimate |
| CP2102 | 1 | Jetson USB | ~20mA / ~0.07W | USB-UART | Verified estimate |
| Waveshare UPS | 1 | 3S 18650, 11.1V / 12.6V | 5V rail rated 5A / 25W | Power + optional I2C | Verified architecture |
| Logic/steering UPS battery pack | 1 | 3S, 11.1V nominal / 12.6V full | 1200mAh / ~13.3Wh | Power | Verified architecture |
| Motor battery pack | 1 | 3S, 11.1V nominal / 12.6V full | 1200mAh / ~13.3Wh | Power | Verified architecture |
| 3S BMS | 1 | 3S Li-ion | 20A module rating | Power | Verified architecture |
| I²C expansion board | 1 | UPS 5V | ~10-20mA / ~0.08W | I2C | Verified estimate |

---
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

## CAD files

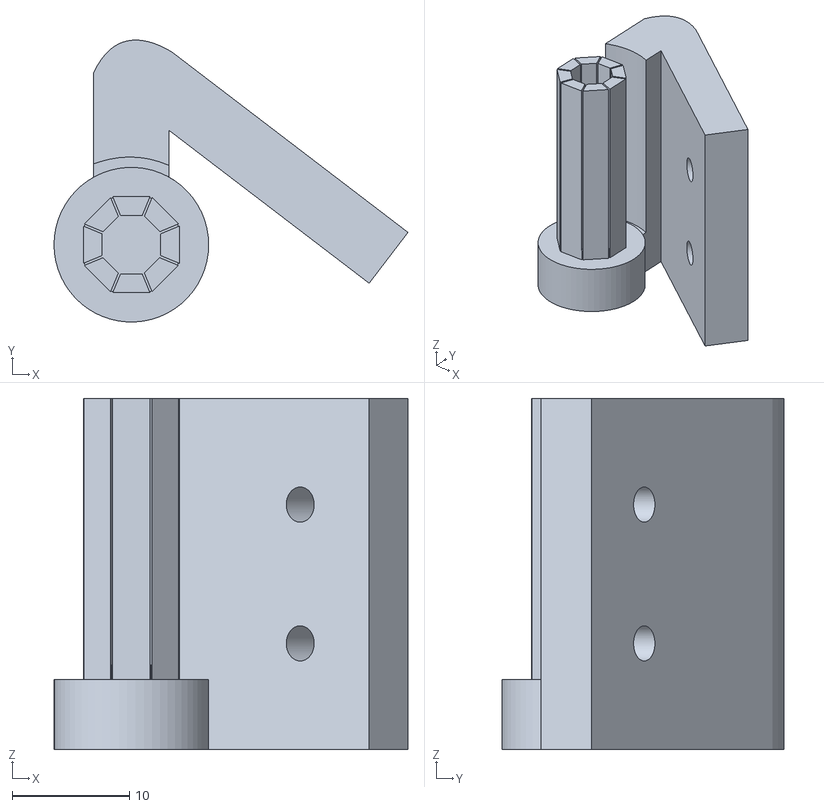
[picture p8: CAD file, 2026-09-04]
Models/cad/Cam_holder_part#3.stl
30.2 x 24.1 x 30.0

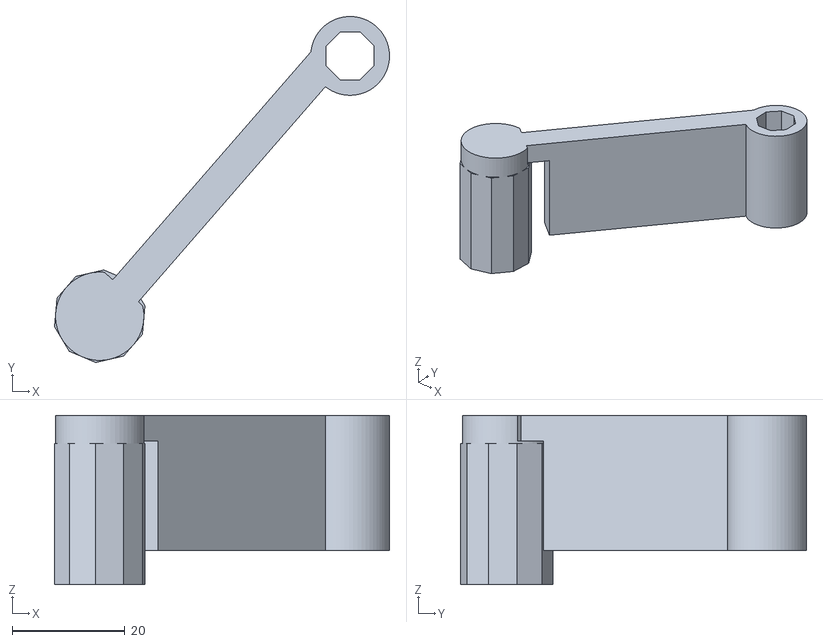
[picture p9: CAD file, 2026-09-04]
Models/cad/Cam_holder_part2#.stl
59.5 x 61.4 x 30.0

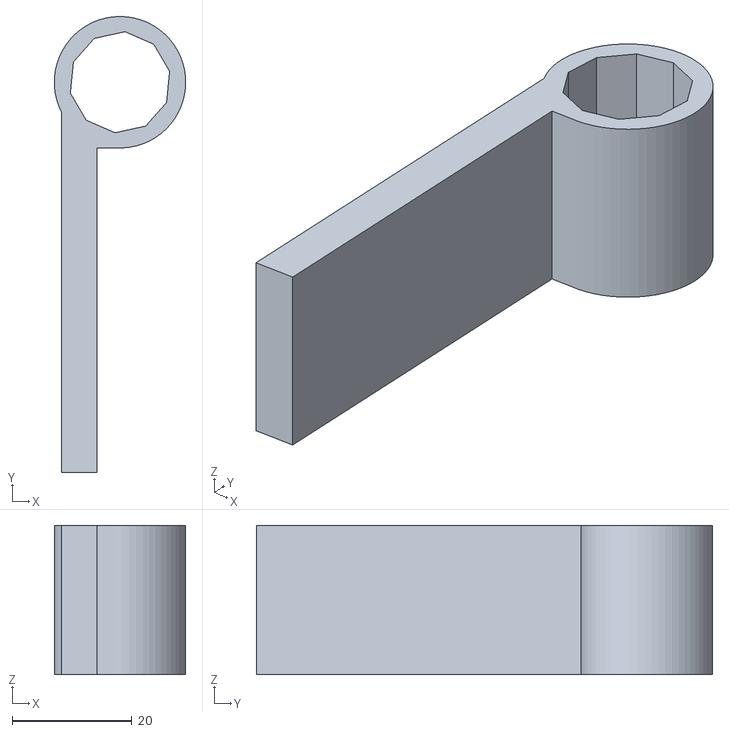
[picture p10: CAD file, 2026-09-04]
Models/cad/Cam_holder_part1#.stl
22.0 x 76.3 x 25.0

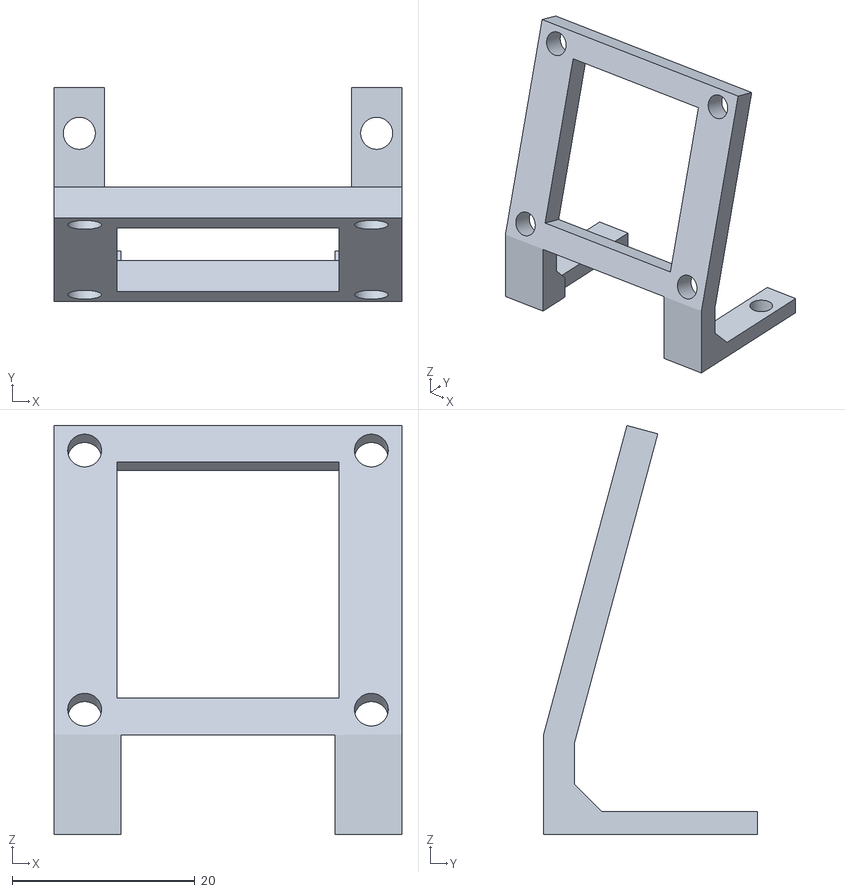
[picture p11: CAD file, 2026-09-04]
Models/cad/OLED_holder.stl
38.0 x 23.4 x 44.7

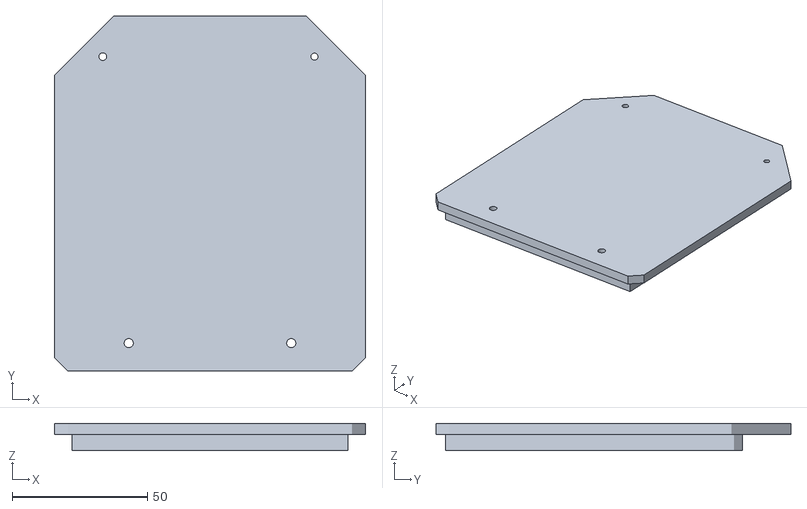
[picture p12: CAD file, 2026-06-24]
Models/cad/Chasis_Top.stl
115.0 x 131.1 x 10.0

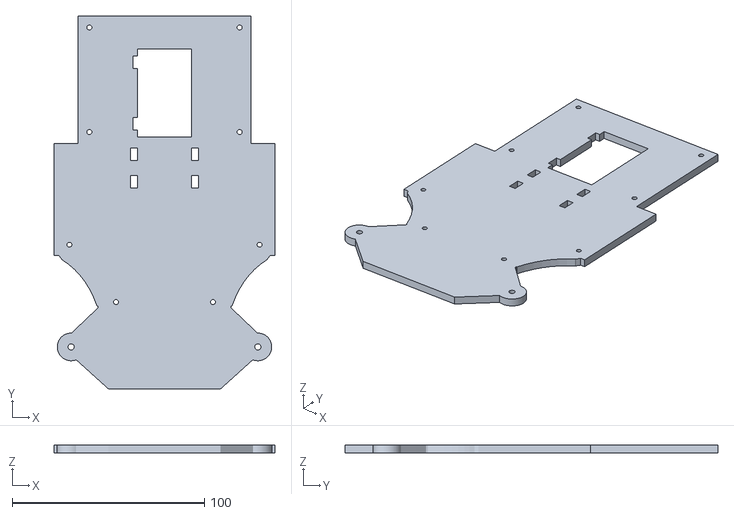
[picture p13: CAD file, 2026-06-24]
Models/cad/Chasis_Bottom.stl
115.0 x 194.2 x 4.00

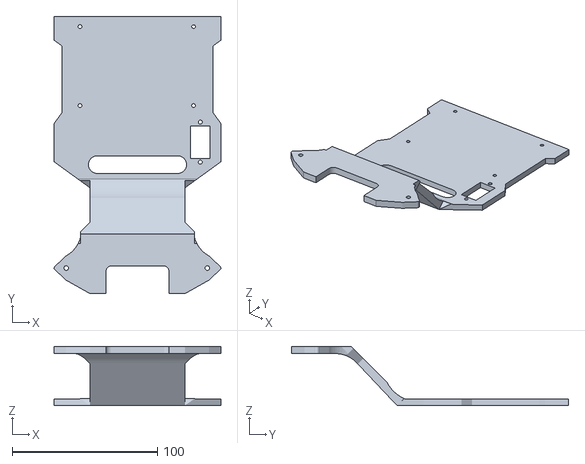
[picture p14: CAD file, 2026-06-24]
Models/cad/Chasis_Middle.stl
115.0 x 190.8 x 40.7

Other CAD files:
Models/cad/Dual_cam_holder_part1_v1.stl

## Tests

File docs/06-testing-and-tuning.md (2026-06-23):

# 06 - Testing and Tuning

**Project:** MetallicMadness / ARBIBOT  
**Category:** WRO 2026 Future Engineers - Self-Driving Cars  
**Document purpose:** Document the testing process used to improve ARBIBOT, including test runs, lap timing, success rate, failure data, tuning parameters, sensor validation, motor validation, obstacle behavior, and lessons learned.

> This document is part of the ARBIBOT engineering documentation package. It is focused on evidence: what was tested, what failed, what changed, and what still needs to be measured.

---

## 1. Purpose of Testing

Testing is the process used to convert ARBIBOT from a working prototype into a reliable competition robot. The robot combines mechanical steering, motor control, distance sensors, camera vision, YOLO inference, UART communication, and state-machine behavior. Because these subsystems interact, most failures only become visible during full driving tests.

The testing process has four main goals:

1. Verify that each subsystem works by itself.
2. Verify that subsystems work together during movement.
3. Measure performance using repeatable metrics.
4. Use failures to improve hardware, software, and tuning.

The most important engineering principle used during testing is:

```text
Do not only record that the robot failed.
Record why it failed, what changed, and whether the change improved the next run.
```

That evidence is what turns a crash into engineering. Without the evidence, it is just an expensive wall handshake.

---

## 2. Testing Categories

ARBIBOT testing is divided into the following categories:

| Category | Purpose |
|---|---|
| Mechanical tests | Check steering range, wheel traction, bumper clearance, drivetrain reliability |
| Power tests | Check runtime, voltage stability, current draw, brownout risk |
| Motor tests | Validate continuous movement, stop, speed, encoder, move-by-degrees |
| Sensor tests | Validate VL53L4CD, VL53L8CX, IMU, sensor addresses, calibration |
| Vision tests | Validate YOLO detection, FPS, confidence thresholds, lighting behavior |
| Open Challenge tests | Validate lane following, corner detection, lap completion |
| Obstacle Challenge tests | Validate red/green pillar detection and pass-side behavior |
| Integration tests | Validate full robot behavior with all systems running together |
| Failure analysis | Record root cause, fix, and retest result |

---

## 3. Main Performance Metrics

The following metrics should be used to evaluate progress.

| Metric | Description | Target / Notes |
|---|---|---|
| Best lap time | Fastest completed lap | 1:05 / 65 seconds |
| Average lap time | Average of clean completed laps | 1:10 / 70 seconds |
| Open Challenge success rate | Percentage of Open Challenge runs completing required behavior | 80% |
| Obstacle Challenge success rate | Percentage of Obstacle Challenge runs obeying red/green signs | 50% |
| Parking success rate | Percentage of parking attempts ending correctly | N/A |
| Corner detection distance | Distance at which corner turn is triggered | Current target around ~100 cm |
| Wall-following error | Difference from target wall distance | Not recorded yet |
| Heading error | Difference between right-front and right-rear sensor values | Not recorded yet |
| YOLO inference time | Time per frame for detection | Not recorded yet |
| YOLO FPS | Inference frames per second on Jetson | Not recorded yet |
| Serial command latency | Time for command/response or fire-and-forget execution | Not recorded yet |
| Stop reliability | Percentage of stop commands executed correctly | Not recorded yet |
| Battery runtime | Operating time under competition load | UPS approx. 24 min; motor battery approx. 2 hr motor-time estimate |

---

## 4. Current Known Progress Summary

The following summary reflects the current development state and should be updated after each major testing session.

| Area | Current status |
|---|---|
| Open Challenge | Single clean laps have been achieved repeatedly. One observed run reached approximately 2.5 of 3 laps before lane-keeping failure. |
| Corner trigger | Front-matrix corner trigger fires reliably at approximately 100 cm after filtering improvements. |
| Wall following | Improved after adding right-front minus right-rear heading correction. |
| Obstacle Challenge | YOLO pillar model detects `Green_Pillar` and `Red_Pillar`; PDI steering logic under tuning. |
| Green pillar issue | Recognition was affected when blocking motor commands slowed the vision loop; non-blocking motor command strategy improved responsiveness. |
| Serial reliability | Critical commands such as start/stop are pulsed several times to reduce dropped-frame risk. |
| Sensor reliability | Side sensor parser was updated for new STM32 firmware; invalid readings are handled more carefully. |
| Mechanical reliability | Bumper and sensor mounts were adjusted to avoid tire rubbing and improve sensor alignment. |

---

## 5. Test Run Log Template

Use this table for every meaningful test run. A run does not need to be successful to be useful. Failed runs are often the best data.

| Run ID | Date | Challenge | Software version | Battery voltage start/end | Speed setting | Result | Laps completed | Time | Main failure / note |
|---|---|---|---|---|---:|---|---:|---:|---|
| RUN-001 | Not recorded yet | Open | v1 | Not recorded yet | Not recorded yet | Failed | Not recorded yet | Not recorded yet | Not recorded yet |
| RUN-002 | Not recorded yet | Open | v2 | Not recorded yet | Not recorded yet | Partial | Not recorded yet | Not recorded yet | Not recorded yet |
| RUN-003 | Not recorded yet | Open | v4 | Not recorded yet | Not recorded yet | Partial | 2.5 | Not recorded yet | Lane-keeping failure |
| RUN-004 | Not recorded yet | Obstacle | main_challenge_02 | Not recorded yet | Not recorded yet | Not recorded yet | Not recorded yet | Not recorded yet | Not recorded yet |

Recommended result labels:

```text
Success
Partial
Failed
Aborted
Mechanical issue
Sensor issue
Vision issue
Software issue
Power issue
```

---

## 6. Version History and Testing Evolution

| Version | Description | Main test result | Decision |
|---|---|---|---|
| v1 - `main_challenge_01.py` | Camera corner detection + open-loop center steering | Basic motion and corner behavior possible, but not stable enough | Improved with sensor feedback |
| v2 - `main_challenge_01_v2.py` | Added PID wall-following and sensor/front-ToF fallbacks | Better lane behavior, but still required more reliable corner trigger | Continued development |
| v3 - `main_challenge_01_v3.py` | Two-right-sensor follow + new VL53L8 4x4 front matrix | Over-complex / unstable during early tests | Abandoned as main base |
| v4 - `main_challenge_01_v4.py` | v2 base + new firmware sensors + front-matrix corner trigger + RF-RR heading wall-follower | Current Open Challenge base; reached repeated clean laps and partial 3-lap run | Current Open Challenge version |
| `main_challenge_02.py` | Pillar YOLO + PDI pass-side steering on v4 scaffolding | Current Obstacle Challenge base | Under tuning |

---

## 7. Mechanical Testing

Mechanical testing focuses on whether the physical robot can execute the commands produced by the software.

### 7.1 Mechanical Test Checklist

| Test | Method | Expected result | Status |
|---|---|---|---|
| Steering center | Set servo to neutral | Wheels point straight | Not recorded yet |
| Maximum left steering | Command full left | No mechanical binding | Not recorded yet |
| Maximum right steering | Command full right | No mechanical binding | Not recorded yet |
| Bumper clearance | Turn wheels fully both directions | Tires do not rub bumper | Improved after redesign |
| Wheel traction | Drive on WRO mat | No slipping under normal acceleration | Improved after replacing thinner wheels |
| Drive axle torque transfer | Start/stop repeatedly | Rear wheels receive torque reliably | Improved after drivetrain change |
| Chassis rigidity | Push/twist gently by hand | No major flex at mounts | Not recorded yet |
| Sensor mount stability | Drive over test laps | Sensor angles do not change | Not recorded yet |

### 7.2 Mechanical Failure Data

| Failure | Observed behavior | Root cause | Fix |
|---|---|---|---|
| Thin wheels slipped on track | Robot did not follow expected path during turns | Low traction/contact area | Switched to wider rubber tires |
| First bumper rubbed tire | Steering movement was restricted | Bumper geometry too close to wheel path | Redesigned bumper and sensor placement |
| Sensor readings unreliable | Distance values did not match expected geometry | Sensors mounted too low | Repositioned sensors |
| Torque transfer issue | Rear drive was inconsistent | Gearbox gear to wheel gear transfer problem | Changed motor/drivetrain approach |
| Steering range/alignment issue | Turning radius and straight tracking inconsistent | Linkage rods and servo arm needed tuning | Adjusted rods, servo arm, and alignment screw |

---

## 8. Motor and Encoder Testing

Motor testing verifies that the STM32, MD10C, motor, and encoder behave correctly before full autonomous driving.

### 8.1 Motor Command Test Sequence

Recommended test sequence:

```text
1. SET SPEED 50%
2. FORWARD continuous for 5 seconds
3. STOP for 2 seconds
4. REVERSE continuous for 5 seconds
5. STOP for 2 seconds
6. FORWARD by degrees
7. STOP
8. REVERSE by degrees
9. STOP
```

### 8.2 Motor Test Log

| Test ID | Command | Expected result | Observed result | Status |
|---|---|---|---|---|
| MOT-01 | `0x0104 SET SPEED` | PWM speed updates | Not recorded yet | Not recorded yet |
| MOT-02 | `0x0004 FORWARD` | Motor moves forward continuously | Not recorded yet | Not recorded yet |
| MOT-03 | `0x0005 REVERSE` | Motor moves reverse continuously | Not recorded yet | Not recorded yet |
| MOT-04 | `0x0103 STOP` | Motor stops immediately | Not recorded yet | Not recorded yet |
| MOT-05 | `0x0101 FORWARD DEGREE` | Motor moves requested degrees | Not recorded yet | Not recorded yet |
| MOT-06 | `0x0102 REVERSE DEGREE` | Motor reverses requested degrees | Not recorded yet | Not recorded yet |
| MOT-07 | Encoder RPM read | RPM changes with motor speed | Not recorded yet | Not recorded yet |

### 8.3 Motor Issues Found

| Problem | Root cause | Fix |
|---|---|---|
| Forward by degree initially over-rotated | Degree conversion / command implementation mismatch | Compared Python command format with STM32 implementation and corrected command behavior |
| Motor did not move with non-blocking command in one version | Fire-and-forget command could be dropped or not sequenced correctly | Pulse critical forward/speed commands and send forward before/interleaved with speed |
| Stop sometimes missed | Serial bus busy during matrix scan | Pulse stop command several times |
| Set-speed affected idle direction | Motor driver command sequencing issue | Send forward first, then speed, and repeat critical commands |

---

## 9. Sensor Testing

Sensor testing verifies distance accuracy, address configuration, XSHUT control, and sensor response stability.

### 9.1 Distance Calibration Method

The VL53 sensors are tested at fixed distances:

```text
120 cm, 110 cm, 100 cm, 90 cm, 80 cm, 70 cm,
60 cm, 50 cm, 40 cm, 30 cm, 20 cm, 10 cm
```

For each distance, the robot is moved to the reference location and the Python sensor test program reads all sensors.

### 9.2 Calibration Data Table

| Real distance | Left VL53L4CD | Right-front VL53L4CD | Right-rear VL53L4CD | Front VL53L8CX | Error / notes |
|---:|---:|---:|---:|---:|---|
| 120 cm | Not recorded yet | Not recorded yet | Not recorded yet | Not recorded yet |  |
| 110 cm | Not recorded yet | Not recorded yet | Not recorded yet | Not recorded yet |  |
| 100 cm | Not recorded yet | Not recorded yet | Not recorded yet | Not recorded yet |  |
| 90 cm | Not recorded yet | Not recorded yet | Not recorded yet | Not recorded yet |  |
| 80 cm | Not recorded yet | Not recorded yet | Not recorded yet | Not recorded yet |  |
| 70 cm | Not recorded yet | Not recorded yet | Not recorded yet | Not recorded yet |  |
| 60 cm | Not recorded yet | Not recorded yet | Not recorded yet | Not recorded yet |  |
| 50 cm | Not recorded yet | Not recorded yet | Not recorded yet | Not recorded yet |  |
| 40 cm | Not recorded yet | Not recorded yet | Not recorded yet | Not recorded yet |  |
| 30 cm | Not recorded yet | Not recorded yet | Not recorded yet | Not recorded yet |  |
| 20 cm | Not recorded yet | Not recorded yet | Not recorded yet | Not recorded yet |  |
| 10 cm | Not recorded yet | Not recorded yet | Not recorded yet | Not recorded yet |  |

### 9.3 Sensor Issues Found

| Problem | Root cause | Fix |
|---|---|---|
| Side sensors returned `-1` | Parser mismatch with new firmware or serial thread starvation | Updated parser and reduced blocking behavior |
| Front matrix showed false close distance | Matrix row included floor cells | Excluded floor-band cells and used a better row selection |
| Turn triggered too early | Lone matrix cell detected corner/wall edge | Required at least two in-band cells before firing |
| Sensor address conflicts possible | Multiple VL53L4CD sensors on one I2C bus | Used XSHUT pins for controlled sensor initialization |
| Sensor values unstable when mounted low | Poor geometry / reading floor or bumper | Repositioned sensor mounts |

---

## 10. Front Matrix Corner Trigger Testing

The front VL53L8CX matrix is used to support corner detection.

### 10.1 Original Problem

The front matrix initially caused two opposite failures:

| Failure | Cause |
|---|---|
| Turned too late | Floor cells in the matrix dragged the calculated median down and hid the true front wall |
| Turned too soon | A single outer-wall corner cell was treated as if it were the front barrier |

### 10.2 Fix

The improved logic:

```text
1. Select the matrix row that best represents the front barrier.
2. Exclude cells likely to see the floor.
3. Accept only values inside a valid distance band.
4. Require at least two valid in-band cells.
5. Fire the corner trigger around the expected distance window.
```

### 10.3 Test Evidence Template

| Test ID | Approach speed | Trigger distance | Cells valid | Result | Notes |
|---|---:|---:|---:|---|---|
| FMT-01 | Not recorded yet | ~100 cm | Not recorded yet | Success | Not recorded yet |
| FMT-02 | Not recorded yet | Not recorded yet | Not recorded yet | Not recorded yet | Not recorded yet |
| FMT-03 | Not recorded yet | Not recorded yet | Not recorded yet | Not recorded yet | Not recorded yet |

---

## 11. Lane-Following Tuning

Lane-following uses the right-front and right-rear VL53L4CD sensors.

### 11.1 Initial Problem

A distance-only controller caused the robot to wander wall-to-wall. The robot knew how far it was from the wall, but it did not know whether it was angled toward or away from the wall.

### 11.2 Improvement

The controller was improved by using the difference between right-front and right-rear readings:

```text
heading_error = right_front_distance - right_rear_distance
```

This heading term helps the robot stay parallel to the wall.

### 11.3 Lane Controller Template

```text
distance_error = target_right_distance - average(right_front, right_rear)
heading_error = right_front - right_rear

steering = Kd * distance_error + Kh * heading_error
```

### 11.4 Tuning Table

| Parameter | Value | Effect |
|---|---:|---|
| Target right distance | Not recorded yet | Desired distance from right wall |
| Distance gain | Not recorded yet | Corrects lateral offset |
| Heading gain | Not recorded yet | Corrects angle relative to wall |
| Steering center | Not recorded yet | Servo neutral |
| Steering clamp | Not recorded yet | Maximum correction |
| Straight speed | Not recorded yet | Motor speed during straight sections |

### 11.5 Lane Test Results

| Test ID | Target distance | Speed | Result | Notes |
|---|---:|---:|---|---|
| LANE-01 | Not recorded yet | Not recorded yet | Wandering | Distance-only PID |
| LANE-02 | Not recorded yet | Not recorded yet | Improved | Added RF-RR heading |
| LANE-03 | Not recorded yet | Not recorded yet | Not recorded yet | Not recorded yet |

---

## 12. Vision and YOLO Testing

Vision testing checks whether the Jetson can detect pillars and track lines with enough speed and reliability.

### 12.1 Pillar Detection Test

| Test ID | Object | Lighting | Distance | Confidence | Result |
|---|---|---|---:|---:|---|
| VIS-01 | Red pillar | Not recorded yet | Not recorded yet | Not recorded yet | Not recorded yet |
| VIS-02 | Green pillar | Not recorded yet | Not recorded yet | Not recorded yet | Not recorded yet |
| VIS-03 | Multiple pillars | Not recorded yet | Not recorded yet | Not recorded yet | Not recorded yet |
| VIS-04 | Partial occlusion | Not recorded yet | Not recorded yet | Not recorded yet | Not recorded yet |
| VIS-05 | Motion blur | Not recorded yet | Not recorded yet | Not recorded yet | Not recorded yet |

### 12.2 Vision Metrics

| Metric | Current / target value |
|---|---:|
| Pillar confidence threshold | 0.30 |
| Corner line confidence threshold | 0.48 |
| YOLO version | Ultralytics YOLO11n |
| Pillar model dataset size | 100 images |
| Line/corner model dataset size | 180 images |
| Inference FPS on Jetson | Approximately 60 FPS |
| Inference time per frame | Approximately 16.7 ms/frame at 60 FPS |
| False positive rate | Not recorded yet |
| False negative rate | Not recorded yet |

### 12.3 Vision Issues Found

| Problem | Root cause | Fix |
|---|---|---|
| Green pillar recognition failed when motor command waited for response | Vision loop was delayed by blocking serial behavior | Used non-blocking/fire-and-forget motor commands where safe |
| Detection unstable under changing lighting | Camera exposure/color differences | Added per-camera color correction |
| Late pillar reaction caused hard steering | Object was acted on only when too close | React earlier and soften PDI gains |
| Target lost during aggressive steering | Full-lock turn moved pillar out of view | Clamp steering and reduce gains |

---

## 13. Obstacle Strategy Testing

Obstacle testing validates red/green rule behavior.

### 13.1 Obstacle Test Matrix

| Test ID | Scenario | Expected behavior | Result | Notes |
|---|---|---|---|---|
| OBS-01 | Single red pillar centered | Pass red on right | Not recorded yet |  |
| OBS-02 | Single green pillar centered | Pass green on left | Not recorded yet |  |
| OBS-03 | Red pillar near left side | Pass right without wall hit | Not recorded yet |  |
| OBS-04 | Green pillar near right side | Pass left without wall hit | Not recorded yet |  |
| OBS-05 | Two pillars visible | Choose nearest/largest valid pillar | Not recorded yet |  |
| OBS-06 | Pillar near corner | Avoid command conflict with cornering | Not recorded yet |  |
| OBS-07 | Lost detection for one frame | Hold last valid detection briefly | Not recorded yet |  |
| OBS-08 | Detection flicker | Debounce prevents repeated reactions | Not recorded yet |  |
| OBS-09 | High steering error | Clamp steering and reduce speed | Not recorded yet |  |
| OBS-10 | Full Obstacle Challenge run | Complete laps while obeying signs | Not recorded yet |  |

### 13.2 PDI Tuning Log

| Test ID | Kp | Ki | Kd | Speed | Steering clamp | Result |
|---|---:|---:|---:|---:|---:|---|
| PDI-01 | Not recorded yet | Not recorded yet | Not recorded yet | Not recorded yet | Not recorded yet | Full-lock / too aggressive |
| PDI-02 | Not recorded yet | Not recorded yet | Not recorded yet | Not recorded yet | Not recorded yet | Softer response |
| PDI-03 | Not recorded yet | Not recorded yet | Not recorded yet | Not recorded yet | Not recorded yet | Not recorded yet |

---

## 14. Open Challenge Testing

Open Challenge testing focuses on three-lap completion without pillars.

### 14.1 Open Challenge Run Log

| Run ID | Software | Speed | Laps completed | Time | Result | Failure / notes |
|---|---|---:|---:|---:|---|---|
| OPEN-01 | v1 | Not recorded yet | Not recorded yet | Not recorded yet | Failed | Early corner logic |
| OPEN-02 | v2 | Not recorded yet | Not recorded yet | Not recorded yet | Partial | PID fallback under tuning |
| OPEN-03 | v3 | Not recorded yet | Not recorded yet | Not recorded yet | Failed/unstable | Over-complex matrix behavior |
| OPEN-04 | v4 | Not recorded yet | 1.0+ | Not recorded yet | Partial/successful lap | Single clean laps achieved repeatedly |
| OPEN-05 | v4 | Not recorded yet | 2.5 | Not recorded yet | Partial | Lane-keeping failure before full 3 laps |

### 14.2 Open Challenge Failure Modes

| Failure | Cause | Fix / planned fix |
|---|---|---|
| Turn too late | Front barrier detection unreliable | Improved front matrix filtering |
| Turn too early | One-cell false trigger | Require multiple valid matrix cells |
| Wall-to-wall wandering | Distance-only lane controller | Add RF-RR heading correction |
| Missed stop / delayed stop | Serial bus busy | Pulse stop command |
| Overcorrection after turn | Steering returns too sharply | Add cooldown and smoother recovery |

---

## 15. Parking Testing

Parking is currently marked N/A because it has not been evaluated as a separate completed metric in the current test data.

### 15.1 Parking Test Plan

| Test ID | Scenario | Expected behavior | Result |
|---|---|---|---|
| PARK-01 | Detect parking section | Robot identifies correct area | Not recorded yet |
| PARK-02 | Align parallel to wall | Side distances show parallel position | Not recorded yet |
| PARK-03 | Enter parking lot partially | Robot enters without touching markers | Not recorded yet |
| PARK-04 | Full parallel park | Robot stops fully inside and parallel | Not recorded yet |
| PARK-05 | Marker avoidance | Robot avoids magenta parking limits | Not recorded yet |

### 15.2 Parking Metrics

| Metric | Value |
|---|---:|
| Parking success rate | N/A |
| Average parking time | Not recorded yet |
| Final wall distance front/rear | Not recorded yet |
| Parallel error | Not recorded yet |
| Marker contact incidents | Not recorded yet |

---

## 16. Power and Runtime Testing

Power testing verifies that the robot can run a full challenge without brownouts, resets, or unstable behavior.

### 16.1 Runtime Test

| Test ID | Start voltage | End voltage | Duration | Load condition | Result |
|---|---:|---:|---:|---|---|
| PWR-01 | Not recorded yet | Not recorded yet | 3 min | Competition run | Not recorded yet |
| PWR-02 | Not recorded yet | Not recorded yet | 10 min | Continuous driving | Not recorded yet |
| PWR-03 | Not recorded yet | Not recorded yet | 20-30 min | Full electronics active | Estimated target | Not recorded yet |

### 16.2 Current Draw Measurements

| Subsystem | Idle current | Typical current | Peak current | Notes |
|---|---:|---:|---:|---|
| Jetson Orin Nano | ~25W typical | ~40W peak | Measured/estimated workload | YOLO11n runtime observed at ~60 FPS |
| STM32F411 | ~40 mA | ~0.13 W | Estimated | Powered from Jetson USB / CP2102 subtree |
| MG996R servo | ~10 mA idle | 500-900 mA normal | 1.5-2.5 A stall | Estimate |
| JGY-370B motor | 0.06-0.09 A no-load | 0.2-0.3 A normal | 1.3-2.0 A stall | Estimate |
| VL53L4CD sensors | ~60 mA total | ~0.30 W total | Estimate | Three side sensors |
| VL53L8CX | ~60 mA typical, ~120 mA peak | ~0.30 W typical | Estimate/spec | Front matrix sensor |

### 16.3 Power Issues to Watch

| Issue | Symptom | Mitigation |
|---|---|---|
| Jetson brownout | Jetson reboots or camera drops | Separate UPS power path |
| Servo voltage dip | Steering jitter or reset | Verify UPS/regulator current margin |
| Motor noise | Sensor/UART errors | Separate motor power and route wires carefully |
| Low battery | Reduced speed or unstable behavior | Monitor voltage before competition run |

---
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

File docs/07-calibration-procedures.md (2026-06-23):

# 07 - Calibration Procedures

**Project:** MetallicMadness / ARBIBOT  
**Category:** WRO 2026 Future Engineers - Self-Driving Cars  
**Document purpose:** Define repeatable calibration procedures for camera setup, YOLO confidence thresholds, VL53 ToF thresholds, servo center, steering limits, and motor speed.

> This document should be used before major test sessions and before competition runs. Calibration values must be updated whenever the camera, bumper, sensors, steering linkage, wheels, motor, or power system changes.

---

## 1. Calibration Philosophy

ARBIBOT depends on several subsystems working together:

- camera vision,
- YOLO inference,
- ToF distance sensing,
- steering servo control,
- motor speed control,
- encoder feedback,
- Jetson-to-STM32 serial communication,
- and challenge state-machine thresholds.

A small mechanical or electrical change can affect software behavior. For example:

- moving a VL53 sensor changes wall-following thresholds,
- changing camera angle changes pillar detection position,
- changing steering linkage changes servo center and steering limits,
- changing motor speed changes required reaction distance,
- changing battery voltage can change motor response and servo behavior.

The goal of calibration is to produce repeatable behavior, not only one lucky successful run.

---

## 2. Calibration Order

Calibration should be performed in this order:

```text
1. Mechanical inspection
2. Power verification
3. Servo center and steering limits
4. Motor direction and speed
5. Encoder validation
6. ToF sensor initialization and distance calibration
7. Front matrix threshold calibration
8. Camera alignment
9. YOLO confidence threshold tuning
10. Lane-following tuning
11. Obstacle PDI tuning
12. Full challenge validation
```

This order matters. Do not tune YOLO steering behavior before the steering center is correct. Do not tune wall-following thresholds before the sensors are physically stable. Do not tune motor speed before battery voltage is reliable.

---

## 3. Calibration Files and Parameters

The following software files contain values that are affected by calibration.

| File | Calibration role |
|---|---|
| `src/main_challenge_01_v4.py` | Open Challenge state machine, corner behavior, speed settings |
| `src/main_challenge_02.py` | Obstacle Challenge behavior, pillar pass-side logic, PDI tuning |
| `src/sensor_distance_v3.py` | ToF parsing, front matrix processing, distance thresholds |
| `src/Pillar_recognition.py` | Pillar detection handling, confidence threshold, screen zones |
| `src/pillar_counter.py` | Pillar debounce and counting logic |
| `src/pid_line_follower.py` | Lane-following PID/PDI gains |
| `src/motor_driver.py` | Motor command timing, speed commands, fire-and-forget behavior |
| `src/servo_controller.py` | Servo center, steering limits, steering command mapping |
| `src/color_tuning.py` | Camera color correction and image tuning |
| STM32 firmware | Sensor initialization, I2C addresses, XSHUT, motor PWM, encoder counts |

---

## 4. Calibration Master Table

Keep the final calibration values here.

| Parameter | Current value | Final value | Notes |
|---|---:|---:|---|
| Camera resolution | 1280x720 | 1280x720 | Jetson GStreamer/OpenCV capture |
| Camera FPS | Approximately 60 FPS pipeline observation | Approximately 60 FPS | YOLO11n runtime observation on Jetson |
| Camera exposure | Auto | Auto / tune if field lighting requires it | Lock only if lighting instability appears |
| Pillar YOLO confidence | 0.30 | 0.30 | Current working value |
| Corner line confidence | 0.48 | 0.48 | Current working value |
| Front matrix trigger distance | ~100 cm | ~100 cm | Current working trigger distance |
| Front matrix valid-cell requirement | >= 2 cells | >= 2 cells | Used to reduce false triggers |
| Left VL53L4CD offset | Not recorded yet | Not recorded yet | mm correction if needed |
| Right-front VL53L4CD offset | Not recorded yet | Not recorded yet | mm correction if needed |
| Right-rear VL53L4CD offset | Not recorded yet | Not recorded yet | mm correction if needed |
| Target right wall distance | Not recorded yet | Not recorded yet | Used by lane controller |
| Servo center | Not recorded yet | Not recorded yet | Neutral straight wheels |
| Servo max left | Not recorded yet | Not recorded yet | Avoid mechanical binding |
| Servo max right | Not recorded yet | Not recorded yet | Avoid mechanical binding |
| Normal motor speed | Not recorded yet | Not recorded yet | Open Challenge straight speed |
| Corner motor speed | Not recorded yet | Not recorded yet | Slower corner approach if needed |
| Obstacle motor speed | Not recorded yet | Not recorded yet | Safer speed near pillars |
| Motor PWM min moving | Not recorded yet | Not recorded yet | Lowest command that moves reliably |
| Motor PWM max safe | Not recorded yet | Not recorded yet | Maximum stable competition speed |
| Encoder ticks per wheel revolution | Not recorded yet | Not recorded yet | Depends on motor and gearbox |
| Wheel diameter | Not recorded yet | Not recorded yet | Needed for distance calculation |
| Battery voltage start | Not recorded yet | Not recorded yet | Before run |
| Battery voltage end | Not recorded yet | Not recorded yet | After 3-minute run |

---

## 5. Required Tools

Recommended tools for calibration:

| Tool | Use |
|---|---|
| Measuring tape or ruler | ToF distance calibration and robot geometry |
| Printed WRO field / test wall | Wall-following and corner testing |
| Laptop connected to Jetson | Run Python scripts and view logs |
| STM32 serial test script | Motor and sensor command validation |
| Multimeter | Battery voltage and power checks |
| Phone camera or external camera | Record calibration runs |
| Stopwatch | Lap timing and motor movement timing |
| Small object / test pillar | YOLO and obstacle behavior testing |
| Marker tape | Mark sensor distances and trigger points |
| Notebook or CSV log | Record final values |

---

## 6. Safety Before Calibration

Before any calibration where the motor can move:

1. Lift the robot so drive wheels do not touch the floor.
2. Verify motor direction.
3. Test STOP command.
4. Keep physical power disconnect available.
5. Do not place fingers near steering linkage or wheels.
6. Do not run the robot with loose wires.
7. Do not calibrate with low battery.

Minimum safety test:

```text
FORWARD 1 second -> STOP
REVERSE 1 second -> STOP
STEER LEFT -> CENTER -> RIGHT -> CENTER
```

---

## 7. Mechanical Pre-Calibration

Software calibration should not begin until the mechanical system is stable.

### 7.1 Mechanical Checklist

| Check | Expected result | Status |
|---|---|---|
| Front wheels straight at servo center | Wheels point forward | Not recorded yet |
| Steering left | No tire rubbing | Not recorded yet |
| Steering right | No tire rubbing | Not recorded yet |
| Front bumper clearance | Bumper does not touch tire | Not recorded yet |
| Sensor mount angle | Sensor faces intended direction | Not recorded yet |
| Camera mount | Camera fixed, no vibration | Not recorded yet |
| Rear wheels | Wheels fixed and not slipping on shaft | Not recorded yet |
| Wires | No cable touches wheels or steering | Not recorded yet |
| Chassis | No loose part | Not recorded yet |

### 7.2 Mechanical Calibration Notes

Record changes here:

| Date | Mechanical change | Calibration affected |
|---|---|---|
| Not recorded yet | Front bumper changed | ToF thresholds, sensor calibration |
| Not recorded yet | Steering linkage adjusted | Servo center, steering limits |
| Not recorded yet | Camera angle changed | YOLO zones, confidence, line/corner model |
| Not recorded yet | Wheel type changed | Motor speed, lane tuning, encoder distance |

---

## 8. Servo Center Calibration

The steering servo must be calibrated before lane-following or obstacle steering.

### 8.1 Goal

Find the servo value that makes the front wheels physically straight.

This value is called:

```text
SERVO_CENTER
```

### 8.2 Procedure

1. Lift the front of the robot.
2. Power the servo controller.
3. Send the current center value.
4. Place the robot on a flat surface.
5. Look from the front and top.
6. Adjust the servo value until both front wheels point straight.
7. Roll the robot forward by hand and confirm it does not drift strongly.
8. Record the final value.
9. Mark the servo horn position physically if useful.

### 8.3 Servo Center Test Table

| Test | Servo value | Observed behavior | Decision |
|---|---:|---|---|
| SC-01 | Not recorded yet | Wheels slightly left | Increase/decrease value |
| SC-02 | Not recorded yet | Wheels slightly right | Increase/decrease value |
| SC-03 | Not recorded yet | Wheels straight | Candidate center |
| SC-04 | Not recorded yet | Robot rolls straight | Final center |

### 8.4 Final Value

```text
SERVO_CENTER = Not recorded yet
```

### 8.5 Notes

Do not fix steering drift only in software if the mechanical center is wrong. First correct the servo center and linkage. Then tune the lane controller.

---

## 9. Steering Limit Calibration

The servo must not command steering beyond the mechanical safe range.

### 9.1 Goal

Find safe left and right steering limits:

```text
SERVO_LEFT_LIMIT
SERVO_RIGHT_LIMIT
```

### 9.2 Procedure

1. Lift the front wheels.
2. Command center.
3. Slowly increase steering left.
4. Stop before the linkage binds or tire touches bumper/chassis.
5. Record the safe left limit.
6. Return to center.
7. Slowly increase steering right.
8. Stop before the linkage binds or tire touches bumper/chassis.
9. Record the safe right limit.
10. Test both limits on the floor at low speed.

### 9.3 Steering Limit Table

| Test | Direction | Servo value | Result | Safe? |
|---|---|---:|---|---|
| SL-01 | Left | Not recorded yet | No binding | Yes/No |
| SL-02 | Left | Not recorded yet | Tire close to bumper | Yes/No |
| SL-03 | Right | Not recorded yet | No binding | Yes/No |
| SL-04 | Right | Not recorded yet | Tire close to bumper | Yes/No |

### 9.4 Final Values

```text
SERVO_LEFT_LIMIT  = Not recorded yet
SERVO_RIGHT_LIMIT = Not recorded yet
```

### 9.5 Steering Clamp

The software should clamp steering commands to avoid unsafe values:

```text
steering_command = clamp(steering_command, SERVO_LEFT_LIMIT, SERVO_RIGHT_LIMIT)
```

For Obstacle Challenge, use a softer clamp than the mechanical maximum. Mechanical maximum is for safety, not normal driving.

---

## 10. Servo Response Calibration

After center and limits are known, verify how steering responds during motion.

### 10.1 Low-Speed Steering Test

| Test | Speed | Steering command | Expected behavior | Result |
|---|---:|---:|---|---|
| SR-01 | Not recorded yet | Center | Robot drives straight | Not recorded yet |
| SR-02 | Not recorded yet | Small left | Smooth left curve | Not recorded yet |
| SR-03 | Not recorded yet | Small right | Smooth right curve | Not recorded yet |
| SR-04 | Not recorded yet | Medium left | Controlled turn | Not recorded yet |
| SR-05 | Not recorded yet | Medium right | Controlled turn | Not recorded yet |

### 10.2 Steering Deadband

If small steering changes do not move the robot enough, define a steering deadband.

```text
SERVO_DEADBAND = Not recorded yet
```

This prevents the controller from producing tiny corrections that do not affect the wheels.

---

## 11. Motor Direction Calibration

The motor direction must match the software command names.

### 11.1 Motor Command IDs

| Command | ID | Expected behavior |
|---|---:|---|
| FORWARD continuous | `0x0004` | Robot moves forward |
| REVERSE continuous | `0x0005` | Robot moves backward |
| STOP | `0x0103` | Motor stops |
| SET SPEED | `0x0104` | PWM/speed changes |
| FORWARD by degrees | `0x0101` | Motor moves forward by encoder degrees |
| REVERSE by degrees | `0x0102` | Motor moves backward by encoder degrees |

### 11.2 Procedure

1. Lift the robot so wheels can rotate freely.
2. Set speed to a low value.
3. Send FORWARD.
4. Verify wheel direction.
5. Send STOP.
6. Send REVERSE.
7. Verify opposite direction.
8. Send STOP.
9. Place robot on the floor.
10. Repeat for 1 second at low speed.

### 11.3 Direction Test Table

| Test | Command | Expected result | Observed result | Pass? |
|---|---|---|---|---|
| MD-01 | FORWARD | Wheels move robot forward | Not recorded yet | Not recorded yet |
| MD-02 | STOP | Motor stops | Not recorded yet | Not recorded yet |
| MD-03 | REVERSE | Wheels move robot backward | Not recorded yet | Not recorded yet |
| MD-04 | STOP | Motor stops | Not recorded yet | Not recorded yet |

### 11.4 Final Direction Status

```text
MOTOR_FORWARD_IS_CORRECT = Not recorded yet
```

If forward and reverse are inverted, fix the firmware or wiring before continuing.

---

## 12. Motor Speed Calibration

Motor speed calibration finds stable speed values for different driving situations.

### 12.1 Goals

Find:

```text
MOTOR_SPEED_MIN_MOVING
MOTOR_SPEED_OPEN_STRAIGHT
MOTOR_SPEED_CORNER
MOTOR_SPEED_OBSTACLE
MOTOR_SPEED_PARKING
MOTOR_SPEED_MAX_SAFE
```

### 12.2 Minimum Moving Speed

The minimum moving speed is the lowest command that moves the robot reliably on the WRO mat.

#### Procedure

1. Place the robot on the field.
2. Command a very low speed.
3. Increase speed gradually.
4. Record the first value where the robot starts moving consistently.
5. Repeat with fully charged battery and partially used battery.

#### Table

| Test | Speed command | Battery voltage | Movement result |
|---|---:|---:|---|
| MS-01 | 20% | Not recorded yet | Not recorded yet |
| MS-02 | 30% | Not recorded yet | Not recorded yet |
| MS-03 | 40% | Not recorded yet | Not recorded yet |
| MS-04 | 50% | Not recorded yet | Not recorded yet |

Final value:

```text
MOTOR_SPEED_MIN_MOVING = Not recorded yet
```

### 12.3 Open Challenge Straight Speed

The Open Challenge speed should be fast enough to complete laps but slow enough for reliable corner detection.

| Test | Speed | Laps completed | Time | Failure / result |
|---|---:|---:|---:|---|
| OS-01 | Not recorded yet | Not recorded yet | Not recorded yet | Not recorded yet |
| OS-02 | Not recorded yet | Not recorded yet | Not recorded yet | Not recorded yet |
| OS-03 | Not recorded yet | Not recorded yet | Not recorded yet | Not recorded yet |

Final value:

```text
MOTOR_SPEED_OPEN_STRAIGHT = Not recorded yet
```

### 12.4 Corner Speed

If the robot turns too late or oversteers at corners, reduce speed before cornering.

| Test | Speed | Corner trigger distance | Turn result |
|---|---:|---:|---|
| CS-01 | Not recorded yet | Not recorded yet | Not recorded yet |
| CS-02 | Not recorded yet | Not recorded yet | Not recorded yet |
| CS-03 | Not recorded yet | Not recorded yet | Not recorded yet |

Final value:

```text
MOTOR_SPEED_CORNER = Not recorded yet
```

### 12.5 Obstacle Speed

Obstacle speed must allow enough time for YOLO detection and steering response.

| Test | Speed | Red pillar result | Green pillar result | Notes |
|---|---:|---|---|---|
| OBMS-01 | Not recorded yet | Not recorded yet | Not recorded yet | Not recorded yet |
| OBMS-02 | Not recorded yet | Not recorded yet | Not recorded yet | Not recorded yet |
| OBMS-03 | Not recorded yet | Not recorded yet | Not recorded yet | Not recorded yet |

Final value:

```text
MOTOR_SPEED_OBSTACLE = Not recorded yet
```

### 12.6 Motor Speed Rule

Do not choose speed based only on straight-line movement. Choose speed based on complete system success:

```text
Best speed = highest speed that still allows stable sensing, vision, steering, and stopping.
```

---

## 13. Encoder Calibration

The motor encoder is used to measure rotation and support degree-based movement.

### 13.1 Required Values

| Parameter | Value |
|---|---:|
| Encoder pulses per motor revolution | 11 PPR base |
| Gearbox reduction ratio | Not recorded yet |
| Effective pulses per output revolution | Not recorded yet |
| Wheel diameter | Not recorded yet |
| Wheel circumference | Not recorded yet |
| Encoder ticks per centimeter | Not recorded yet |

### 13.2 Wheel Circumference

Measure the wheel diameter and calculate:

```text
wheel_circumference = pi * wheel_diameter
```
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

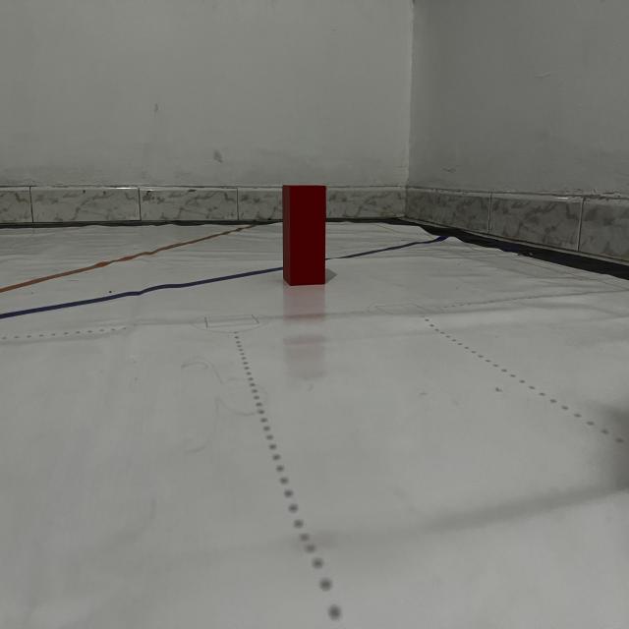
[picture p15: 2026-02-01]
src/NVIDIA/test/images/IMG_8641_jpg.rf.719892036158dc23723461b034b419cc.jpg

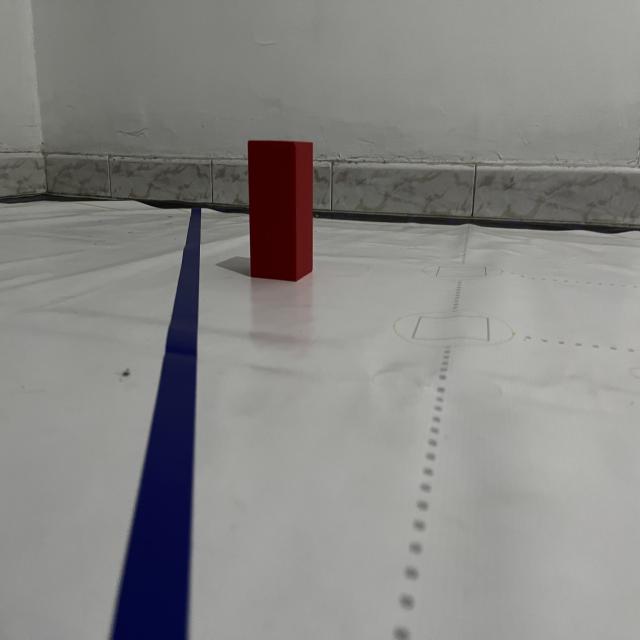
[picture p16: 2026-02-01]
src/NVIDIA/test/images/IMG_8644_jpg.rf.de371ffc3d156a4e5ceafddc6f9a14a6.jpg

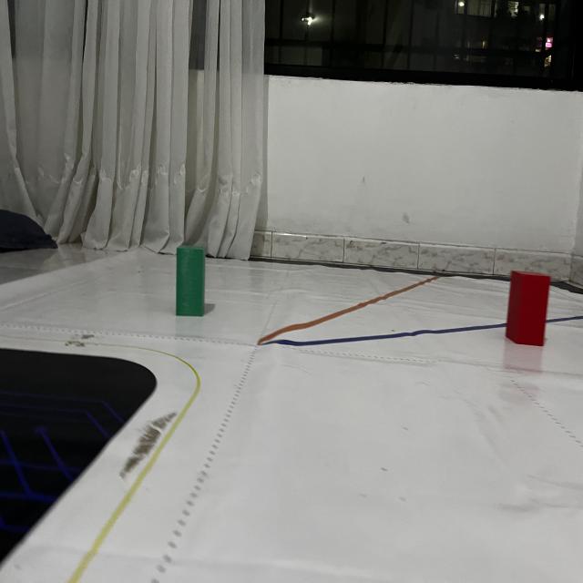
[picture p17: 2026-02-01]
src/NVIDIA/test/images/IMG_8691_jpg.rf.32a52f122e4a431db94f3f732d36429a.jpg

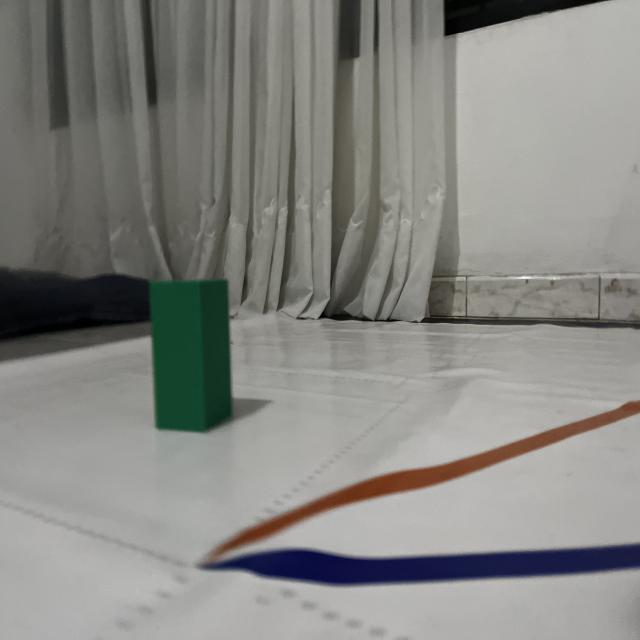
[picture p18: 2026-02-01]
src/NVIDIA/test/images/IMG_8685_jpg.rf.d6f09e773fc2220661698fc5aed85b83.jpg

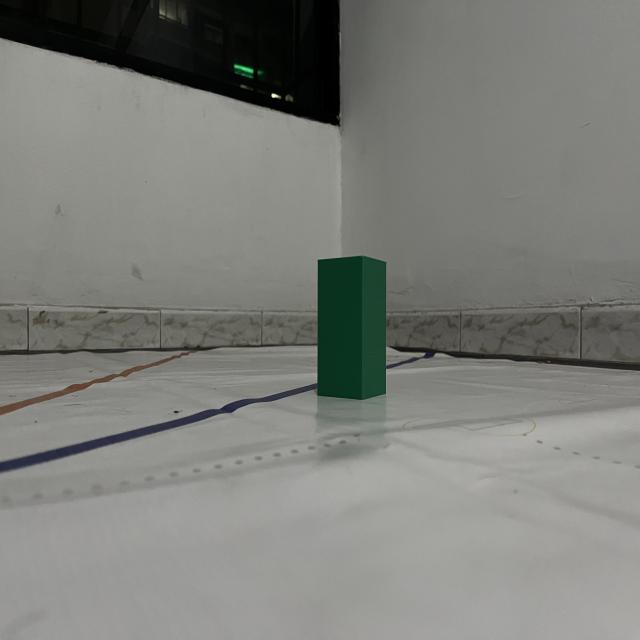
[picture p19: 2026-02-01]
src/NVIDIA/test/images/IMG_8601_jpg.rf.5b77226d5341989ca59e3b459a5b2cce.jpg

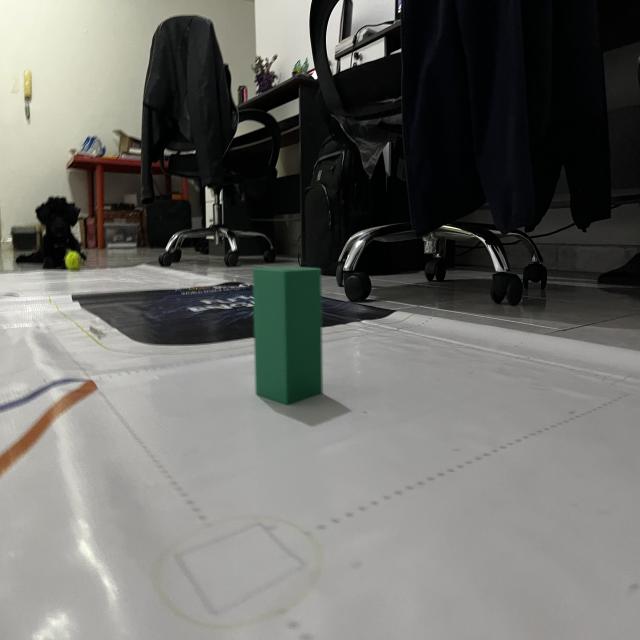
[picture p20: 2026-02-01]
src/NVIDIA/test/images/IMG_8676_jpg.rf.586c39a2e1cee27030529af252ddea6b.jpg

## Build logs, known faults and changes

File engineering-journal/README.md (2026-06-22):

# Engineering Journal

This folder contains the Engineering Journal for **MetallicMadness / ARBIBOT**, the WRO Future Engineers self-driving car project.

The Engineering Journal documents the complete engineering process behind the robot, including mechanical design, power architecture, sensor placement, software architecture, obstacle strategy, testing, failures, improvements, and reproducibility information.

## Files

| File / Folder | Description |
|---|---|
| `engineering-journal.md` | Editable Markdown version of the Engineering Journal. This is the source document used for updates. |
| `engineering-journal.pdf` | PDF version prepared for judges, review, printing, and submission. |
| `images/` | Supporting images used in the journal, including robot photos, wiring diagrams, subsystem images, and architecture references. |

## Purpose

The goal of this documentation is to show not only the final robot, but also the engineering reasoning used to design and improve it. The journal explains why components were selected, how subsystems interact, what problems were found during testing, and how the design evolved through iteration.

## Main Topics Covered

- Team and project overview
- WRO design constraints
- Mechanical mobility and steering design
- Power system and sensor architecture
- Jetson Orin Nano and STM32F411 system roles
- Camera, YOLO model, and obstacle detection strategy
- UART communication between Jetson and STM32
- Testing results, failures, and improvements
- Build, setup, and reproducibility notes

## Update Policy

The Markdown file should be updated first. After major changes, the PDF version should be regenerated so both files remain synchronized.

## Recommended Git Workflow

```bash
git add engineering-journal/
git commit -m "docs: add WRO engineering journal"
git push
```

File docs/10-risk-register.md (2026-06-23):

# 10 - Risk Register

**Project:** MetallicMadness / ARBIBOT  
**Category:** WRO 2026 Future Engineers - Self-Driving Cars  
**Document purpose:** Identify the main failure modes that can affect ARBIBOT during development, testing, and competition, and define mitigation, detection, and recovery strategies.

> This document is a living engineering risk register. It should be updated whenever a new failure appears during testing or when an existing mitigation is improved.

---

## 1. Risk Register Purpose

ARBIBOT combines mechanical steering, motor control, distance sensors, camera vision, YOLO inference, UART communication, batteries, and challenge-specific software. A failure in any one of these subsystems can cause the full robot to fail.

The purpose of this risk register is to:

1. Identify the most important technical risks.
2. Explain how each risk appears during testing.
3. Estimate impact and probability.
4. Define prevention and detection methods.
5. Define recovery behavior where possible.
6. Connect each risk to real test evidence or known robot behavior.

The risk register helps the team make better engineering decisions instead of reacting randomly when the robot fails.

---

## 2. Risk Scoring Method

Each risk is scored using three values:

| Value | Meaning |
|---|---|
| Probability | How likely the risk is to happen |
| Impact | How serious the effect is if it happens |
| Detection difficulty | How hard it is to notice before it causes failure |

Score range:

| Score | Level |
|---:|---|
| 1 | Very low |
| 2 | Low |
| 3 | Medium |
| 4 | High |
| 5 | Very high |

Priority is calculated as:

```text
risk_priority = probability * impact * detection_difficulty
```

The score is not perfect, but it helps the team focus on the most dangerous problems first.

---

## 3. Risk Priority Levels

| Priority score | Level | Meaning |
|---:|---|---|
| 1-15 | Low | Monitor during testing |
| 16-35 | Medium | Add mitigation and test regularly |
| 36-60 | High | Must be addressed before competition |
| 61-125 | Critical | Immediate engineering action required |

---

## 4. Summary Risk Table

| ID | Risk | Subsystem | Probability | Impact | Detection difficulty | Priority | Level |
|---|---|---|---:|---:|---:|---:|---|
| R-001 | Camera glare / lighting changes | Vision | 4 | 4 | 3 | 48 | High |
| R-002 | Bad pillar detection | Vision / Strategy | 4 | 5 | 3 | 60 | High |
| R-003 | Sensor noise or invalid ToF readings | Sensors | 4 | 4 | 3 | 48 | High |
| R-004 | UART timeout or dropped serial frame | Communication | 4 | 4 | 4 | 64 | Critical |
| R-005 | Motor command blocking vision loop | Software / Communication | 4 | 5 | 4 | 80 | Critical |
| R-006 | Weak battery or voltage drop | Power | 3 | 5 | 3 | 45 | High |
| R-007 | Jetson brownout or reboot | Power / Compute | 3 | 5 | 3 | 45 | High |
| R-008 | Servo jitter or steering power dip | Power / Steering | 3 | 4 | 3 | 36 | High |
| R-009 | Wheel slip | Mechanical | 3 | 4 | 3 | 36 | High |
| R-010 | Steering misalignment | Mechanical / Control | 3 | 4 | 2 | 24 | Medium |
| R-011 | Bumper or sensor mount interference | Mechanical | 2 | 4 | 2 | 16 | Medium |
| R-012 | I2C address conflict | Sensors / Firmware | 2 | 5 | 3 | 30 | Medium |
| R-013 | Front matrix false corner trigger | Sensors / Strategy | 4 | 4 | 3 | 48 | High |
| R-014 | Corner detected too late | Sensors / Strategy | 3 | 5 | 3 | 45 | High |
| R-015 | Over-aggressive PDI steering | Obstacle strategy | 3 | 4 | 3 | 36 | High |
| R-016 | Robot loses pillar target | Vision / Strategy | 3 | 4 | 3 | 36 | High |
| R-017 | Stop command not executed | Motor / Communication | 3 | 5 | 4 | 60 | High |
| R-018 | Incorrect motor direction | Motor / Firmware | 2 | 5 | 2 | 20 | Medium |
| R-019 | Encoder feedback error | Motor / Odometry | 2 | 3 | 3 | 18 | Medium |
| R-020 | Wiring disconnect during run | Electrical | 2 | 5 | 3 | 30 | Medium |
| R-021 | Repository file too large | Documentation | 3 | 2 | 1 | 6 | Low |
| R-022 | Missing test data | Documentation / Validation | 4 | 3 | 1 | 12 | Low |
| R-023 | Parking behavior incomplete | Strategy | 3 | 4 | 3 | 36 | High |
| R-024 | Model not trained for competition lighting | Vision | 4 | 4 | 3 | 48 | High |
| R-025 | Sensor calibration drift after mechanical changes | Sensors / Mechanical | 3 | 4 | 3 | 36 | High |

---

## 5. Critical Risks

The following risks have the highest priority and should be tested frequently before competition:

| Risk | Reason |
|---|---|
| UART timeout or dropped serial frame | Can cause missed motor stop, stale sensor data, or command failure |
| Motor command blocking vision loop | Can cause missed pillar detection and wrong obstacle behavior |
| Bad pillar detection | Can cause incorrect red/green pass-side decision |
| Weak battery or voltage drop | Can cause resets, slow movement, servo jitter, or sensor instability |
| Sensor noise or invalid ToF readings | Can cause bad wall following, false corners, or late turns |

---

## 6. Detailed Risk Records

---

## R-001 - Camera Glare / Lighting Changes

### Description

Glare, shadows, strong reflections, or uneven lighting can affect the camera image. This can reduce YOLO confidence, change apparent pillar color, or make floor lines harder to detect.

### Subsystem affected

- Jetson camera
- YOLO inference
- line/corner detection
- obstacle detection
- challenge strategy

### Causes

- bright overhead lights,
- reflections from the WRO field,
- camera auto-exposure changes,
- shadows from the robot or people,
- pillar color appearance changing with angle,
- lens contamination or fingerprints.

### Symptoms

- red or green pillar confidence drops,
- pillar is detected late,
- pillar class changes between frames,
- corner line detection becomes unstable,
- false positives appear on floor or wall,
- robot reacts too late.

### Impact

High. The robot may pass a pillar on the wrong side or fail to detect a corner/visual reference.

### Mitigation

- Use YOLO instead of simple HSV thresholding.
- Add color correction in `color_tuning.py`.
- Test under several lighting conditions.
- Avoid relying on one frame only.
- Use confidence thresholds and detection smoothing.
- Record example images from bad lighting and add them to the dataset.
- Clean camera lens before every run.
- Lock or tune camera exposure if possible.

### Detection method

- Monitor YOLO confidence during test runs.
- Save screenshots of missed detections.
- Compare detection results under different light positions.
- Check whether failure appears only under certain lighting.

### Recovery behavior

- If detection is lost briefly, hold last valid detection for a short timeout.
- Fall back to wall following if no valid pillar is visible.
- Avoid sudden full-lock steering based on one low-confidence detection.

### Status

Open. Needs final lighting test under competition-like conditions.

---

## R-002 - Bad Pillar Detection

### Description

The robot may fail to detect a red or green pillar, detect the wrong color, or select the wrong pillar when multiple objects are visible.

### Subsystem affected

- YOLO model
- camera pipeline
- `Pillar_recognition.py`
- `pillar_counter.py`
- obstacle state machine
- steering controller

### Causes

- insufficient training data,
- poor lighting,
- motion blur,
- partial occlusion,
- pillar too far away,
- pillar too close to image edge,
- confidence threshold too high or too low,
- another object incorrectly classified as pillar,
- robot moving too fast for inference timing.

### Symptoms

- robot does not react to pillar,
- robot reacts too late,
- robot passes red/green pillar on wrong side,
- robot oscillates between detections,
- robot chooses a farther pillar instead of nearest pillar,
- detection flickers between red and green.

### Impact

Very high. In the Obstacle Challenge, incorrect pillar detection directly causes strategy failure.

### Mitigation

- Keep using YOLO classes `Green_Pillar` and `Red_Pillar`.
- Select nearest/largest valid pillar using bounding-box area.
- Use screen-zone logic to understand left/center/right position.
- Debounce detections across frames.
- Reduce motor speed near obstacles if needed.
- Add more training data with real field lighting.
- Include examples of close, far, left-edge, right-edge, and partially occluded pillars.
- Tune confidence threshold.
- Log detection class, confidence, center-X, and area during runs.

### Detection method

- Review video with YOLO overlay.
- Log every detection frame.
- Count false positives, false negatives, and wrong-color classifications.
- Test each color separately and then mixed.

### Recovery behavior

- If pillar disappears briefly, keep last valid target for a short time.
- If confidence is too low, prefer safe lane following instead of aggressive steering.
- If two detections appear, choose the closest/largest valid object.
- If classification flickers, require stable color for multiple frames.

### Status

Open. Pillar strategy works in development but requires more full Obstacle Challenge run data.

---

## R-003 - Sensor Noise or Invalid ToF Readings

### Description

VL53 distance sensors may return invalid values, noisy readings, floor reflections, or inconsistent measurements. This can affect wall following, corner detection, and obstacle distance estimation.

### Subsystem affected

- VL53L4CD side sensors
- VL53L8CX front matrix sensor
- I2C bus
- STM32 firmware
- Jetson sensor parser
- lane-following controller

### Causes

- sensor mounted too low,
- sensor sees floor instead of wall,
- angled surface reflection,
- I2C communication issue,
- out-of-range measurement,
- sensor startup/address problem,
- matrix cell sees irrelevant object,
- serial parser mismatch,
- sensor blocked by bumper or cable.

### Symptoms

- `-1` distance value,
- sudden distance spikes,
- robot steers toward wall,
- robot drifts away from wall,
- corner triggers too early,
- corner triggers too late,
- front matrix reports false close obstacle.

### Impact

High. The robot can hit walls, turn too early, or fail to turn.

### Mitigation

- Use last valid reading when new value is invalid.
- Reject out-of-range values.
- Apply median or simple filtering.
- Check sensor status values.
- Use two right-side sensors for heading correction.
- For front matrix, require multiple valid cells.
- Exclude cells known to see floor or irrelevant surfaces.
- Verify sensor mounting height and angle.
- Use XSHUT initialization for address control.

### Detection method

- Run fixed-distance calibration at 120, 110, 100, 90, 80, 70, 60, 50, 40, 30, 20, 10 cm.
- Log raw and filtered sensor values.
- Print matrix values during corner approach.
- Compare right-front and right-rear readings while robot is parallel to wall.

### Recovery behavior

- If one side sensor is invalid, temporarily rely on the other side sensor or last valid value.
- If front matrix is invalid, avoid triggering a corner based on one bad frame.
- If too many sensors are invalid, slow down or stop.

### Status

Partially mitigated. Parser and front matrix filtering were improved, but final calibration data is still needed.

---

## R-004 - UART Timeout or Dropped Serial Frame

### Description

The Jetson and STM32 communicate through a custom UART protocol. A command frame or response frame can be delayed, corrupted, or missed.

### Subsystem affected

- Jetson serial code
- STM32 serial protocol
- motor commands
- sensor requests
- command response handling
- stop/start behavior

### Causes

- serial bus busy with sensor polling,
- matrix read taking too long,
- blocking wait in wrong thread,
- checksum mismatch,
- incomplete frame,
- USB serial latency,
- buffer overflow,
- command sent while another response is pending,
- electrical noise.

### Symptoms

- motor command ignored,
- stop command missed,
- sensor data does not update,
- timeout exception,
- stale values displayed,
- robot continues moving when it should stop,
- Jetson and STM32 get out of sync.

### Impact

Very high. A missed STOP or delayed sensor response can cause crash or wrong challenge behavior.

### Mitigation

- Use framed protocol with start byte, length, command ID, checksum, and end byte.
- Keep one owner for serial reads.
- Avoid multiple threads reading from the same port.
- Use non-blocking motor commands where safe.
- Pulse critical commands such as STOP and FORWARD.
- Add command timeouts.
- Flush stale bytes if frame parsing fails.
- Log command ID and response text.
- Use checksums to reject bad frames.

### Detection method

- Log every command sent and response received.
- Count timeouts per run.
- Add timestamp around command send/response.
- Test motor and sensor commands separately before full run.
- Reproduce failure while reading front matrix and sending STOP.

### Recovery behavior

- Retry critical command.
- Send STOP multiple times.
- If serial link fails repeatedly, stop the robot or enter safe mode.
- Reset parser state after invalid frame.

### Status

Critical and partially mitigated. Critical commands are pulsed, and blocking serial behavior has been reduced.

---

## R-005 - Motor Command Blocking Vision Loop

### Description

If motor command functions wait for a response while the camera/YOLO loop needs to run, the robot can miss visual detections. This was observed when green pillar recognition improved after changing motor command behavior to avoid blocking.

### Subsystem affected

- Jetson software
- motor driver wrapper
- serial communication
- YOLO loop
- obstacle strategy

### Causes

- `wait_response=True` during active driving,
- motor command uses same serial link as sensor requests,
- serial read conflict between sensor and motor code,
- command timeout pauses main loop,
- motor function blocks while camera frames are skipped.

### Symptoms

- YOLO detection becomes slow or uneven,
- green pillar detection fails during movement,
- robot sees pillar only when stopped,
- motor command works but recognition fails,
- camera display updates at uneven pace.

### Impact

Critical. Obstacle behavior depends on timely vision.

### Mitigation

- Use fire-and-forget motor commands when safe.
- Let sensor thread own serial reads.
- Do not block camera loop waiting for motor response.
- Pulse critical motor commands instead of waiting once.
- Decouple camera inference from motor serial handling.
- Keep motor commands short.
- Use cached sensor values instead of blocking sensor calls inside vision loop.

### Detection method

- Measure camera FPS with and without motor commands.
- Measure YOLO inference interval during driving.
- Log motor command timestamps.
- Check whether detections appear delayed during serial waits.
- Test green pillar detection while motor is moving.

### Recovery behavior

- If camera FPS drops below minimum, reduce motor speed or pause non-critical sensor reads.
- If command response blocks, timeout quickly and continue vision loop.
- If obstacle detection is uncertain, slow down instead of steering aggressively.

### Status

Critical and actively mitigated. Continue testing with full obstacle runs.

---

## R-006 - Weak Battery or Voltage Drop

### Description

ARBIBOT uses two independent 3S battery systems:

```text
System A — Logic and Steering:
Waveshare UPS, 3 × 18650, 11.1V nominal / 12.6V full / ~13.3Wh

System B — Drive:
Separate 3S 18650 motor battery -> 3S 20A BMS -> Cytron MD10C -> 12V JGY-370B motor
```

The runtime calculation shows enough energy margin for a 3-minute WRO round. However, weak cells, low charge, poor connectors, or voltage sag can still cause serious failures.

### Subsystem affected

- Waveshare UPS
- logic/steering 3S battery pack
- motor 3S battery pack
- 3S 20A BMS
- Jetson Orin Nano
- steering servo
- STM32
- camera
- VL53 sensors
- motor driver

### Causes

- low state of charge,
- weak or aged 18650 cells,
- high-current servo movement,
- Jetson workload peak,
- motor stall,
- poor connector contact,
- long wires or voltage drop,
- repeated test runs without charging,
- cells not able to support peak-current events.

### Symptoms

- robot slows down over time,
- steering jitter,
- Jetson reboot,
- camera disconnect,
- STM32 reset,
- USB serial disconnect,
- motor weak or inconsistent,
- sensor readings become unstable,
- stop/start behavior changes with battery level.

### Impact

Very high. Power instability can cause full robot failure.

### Current power-budget status

| Item | Status |
|---|---|
| UPS energy | ~13.3Wh |
| UPS average load | ~29W |
| UPS runtime at 85% efficiency | ~24 min |
| Motor battery energy | ~13.3Wh |
| Motor runtime estimate | ~2 hr motor-time |
| WRO round length | 3 min |
| Runtime margin | Good |
| Remaining concern | Peak-current sag under Jetson load + servo stall |

### Mitigation

- Charge both 3S packs before each test session.
- Measure voltage before and after each run.
- Keep motor and electronics power domains separated.
- Use UPS module for Jetson, sensors, and steering.
- Use the 3S BMS for motor battery protection.
- Check connectors and wire gauge.
- Avoid motor stall.
- Avoid steering commands that hold the servo at mechanical limits.
- Add battery voltage to the test log.
- Replace weak 18650 cells if voltage sag is observed.

### Detection method

- Measure start and end voltage of both battery systems.
- Observe voltage under acceleration and aggressive steering.
- Run YOLO11n while steering aggressively.
- Watch for Jetson reboot, camera dropout, USB serial disconnect, or servo glitch.
- Check whether failures happen late in a test session.
- Test motor runtime separately from Jetson/servo runtime.

### Recovery behavior

- Stop testing when voltage becomes unstable.
- Recharge or replace battery packs.
- Reduce steering aggressiveness if servo load causes sag.
- Do not continue autonomous testing with unstable voltage.
- If sag is confirmed, use higher-discharge 18650 cells and add a 1000µF or larger capacitor across the servo 5V rail.

### Status

Partially closed. Energy/runtime margin is solved. Peak-current sag remains the main verification item.

---

## R-007 - Jetson Brownout or Reboot

### Description

The Jetson Orin Nano may reboot if the UPS battery or regulator path cannot support a workload spike. Since the Jetson runs YOLO11n vision, camera processing, navigation logic, and serial command output, a reboot causes immediate autonomous failure.

### Subsystem affected

- Jetson Orin Nano
- Waveshare UPS
- IMX477 camera
- USB serial devices
- YOLO11n process
- navigation logic
- serial control from Jetson

### Causes

- Jetson workload peak around 40W,
- steering servo high-current event occurring at the same time,
- weak 18650 UPS cells,
- low UPS charge,
- loose power connector,
- voltage sag during aggressive steering,
- USB/CSI devices dropping during power dip.

### Symptoms

- camera stream stops,
- SSH connection drops,
- Jetson boot messages appear,
- robot stops making decisions,
- serial commands stop,
- YOLO process exits,
- USB devices reconnect.

### Impact

Very high.

### Current analysis

The UPS has enough energy for the 3-minute WRO round, but the worst-case instantaneous load can approach:

```text
Jetson peak: ~40W
Servo stall reflected to battery side: ~1.3A equivalent
Estimated UPS pack peak draw: ~4.5A to 5A
```

For 1200mAh cells, this is approximately a 4C peak draw. The risk depends on the real discharge capability of the installed cells.

### Mitigation

- Use stable UPS power path.
- Fully charge the UPS battery pack before testing.
- Keep Jetson power separate from motor power.
- Avoid servo mechanical binding.
- Monitor Jetson uptime during aggressive steering tests.
- Use secure power connectors.
- If sag is observed, use higher-discharge 18650 cells.
- Add a 1000µF or larger capacitor across the servo 5V rail if needed.

### Detection method

- Watch system uptime.
- Check `dmesg` after failure.
- Monitor for USB/camera reconnects.
- Run YOLO11n stress test while steering aggressively.
- Perform a full 3-minute run and inspect for resets or dropped camera frames.

### Recovery behavior

- If Jetson reboots during testing, stop robot and do not continue run.
- Investigate power and thermal logs.
- Recharge or replace UPS cells.
- Reduce servo load and check mechanical steering friction.

### Status

High risk until peak-current sag is empirically tested.

---

## R-008 - Servo Jitter or Steering Power Dip

### Description

The MG996R servo can draw high current, especially when steering under load. The current budget shows normal steering around 0.5–0.9A and stall up to approximately 2.5A from the UPS 5V rail.

### Subsystem affected

- steering servo
- Pololu servo controller
- UPS 5V rail
- Jetson power stability
- mechanical steering linkage
- lane controller
- obstacle controller

### Causes

- servo under heavy load,
- steering linkage binding,
- power rail voltage drop,
- weak UPS battery,
- servo trying to hold against mechanical limit,
- aggressive steering commands,
- obstacle PDI gain or clamp too high.

### Symptoms

- front wheels shake,
- steering response inconsistent,
- robot oscillates,
- Pololu controller resets,
- Jetson or STM32 disturbed by voltage dip,
- servo becomes hot.

### Impact

High. Steering instability affects every challenge.

### Current rail check

The UPS 5V rail is rated for approximately 5A / 25W.

Expected 5V peak load:

```text
servo stall: ~2.5A
sensors + I²C board: ~0.14A
total: ~2.6A
```

This is within the 5A rail rating. The main risk is not the rail rating itself, but peak-current sag on the UPS battery pack during simultaneous Jetson load and servo load.

### Mitigation

- Avoid commanding beyond mechanical limits.
- Tune steering clamp.
- Verify linkage does not bind.
- Reduce PDI/PID gains if steering oscillates.
- Check servo horn and linkage screw tightness.
- Add a 1000µF or larger capacitor across the servo 5V rail if voltage dips are observed.
- Use higher-discharge UPS cells if sag appears.

### Detection method

- Command left/right steering while robot is lifted.
- Command steering while robot is on the mat.
- Listen for servo strain at endpoints.
- Watch for resets during steering.
- Check if jitter increases when battery is low.
- Test aggressive steering while YOLO11n is running.

### Recovery behavior

- Reduce steering command range.
- Stop test if servo overheats.
- Recenter steering and restart calibration.
- Recharge or replace UPS cells if jitter appears only at lower battery levels.

### Status

High risk during aggressive obstacle steering until full-load steering test is completed.

---

## R-009 - Wheel Slip

### Description

Wheel slip reduces control accuracy because the robot does not move according to expected steering and motor commands.

### Subsystem affected

- wheels
- drivetrain
- lane control
- obstacle avoidance
- encoder feedback

### Causes

- thin wheels,
- dusty field,
- high acceleration,
- aggressive turning,
- low weight on drive axle,
- tire material not gripping mat.

### Symptoms

- robot slides outward in turns,
- encoder suggests movement but robot path differs,
- lane controller overcorrects,
- obstacle pass path becomes unpredictable,
- lap time inconsistent.

### Impact

High.

### Mitigation

- Use wider rubber wheels.
- Clean wheels before runs.
- Avoid sudden acceleration.
- Tune speed and steering clamp.
- Ensure rear axle traction is adequate.
- Keep robot weight balanced.

### Detection method

- Video review of turns.
- Compare encoder movement with actual field position.
- Watch for lateral sliding during cornering.

### Recovery behavior

- Reduce speed.
- Use smoother steering.
- Clean or replace wheels.

### Status

Improved after wheel change, but still monitor during fast runs.

---

## R-010 - Steering Misalignment

### Description

If the steering is not centered, the robot drifts even when commanded straight.

### Subsystem affected

- steering linkage
- servo controller
- lane-following software
- mechanical alignment

### Causes

- linkage rods unequal,
- servo horn installed off-center,
- screw alignment not set,
- mechanical play,
- wheel toe angle incorrect,
- servo center value wrong.

### Symptoms

- robot drifts left or right on straight command,
- PID constantly corrects one direction,
- turning radius differs left vs right,
- robot exits corners inconsistently.

### Impact

Medium to high.

### Mitigation

- Mechanically align wheels before software tuning.
- Record final servo center value.
- Use adjustment screw for front-wheel alignment.
- Test straight driving without wall-following correction.
- Recheck alignment after mechanical impacts.

### Detection method

- Drive straight on open section.
- Lift robot and check neutral wheel angle.
- Log steering correction while robot should be centered.

### Recovery behavior

- Recenter servo.
- Adjust linkage and alignment screw.
- Retune PID only after mechanical alignment is fixed.

### Status

Medium. Needs final documented servo center and steering limits.

---

## R-011 - Bumper or Sensor Mount Interference

### Description

The front bumper or sensor mounts can interfere with wheel steering or block sensor view.

### Subsystem affected

- mechanical chassis
- front steering
- distance sensors
- camera view

### Causes

- bumper too close to tires,
- sensor bracket too low,
- cable protruding into wheel path,
- 3D-printed part deformation,
- screws too long.

### Symptoms

- tire rubs bumper at full steering,
- steering servo strains,
- distance sensor reads bumper or floor,
- robot behaves differently left vs right,
- visible mechanical contact.

### Impact

Medium.

### Mitigation

- Check full steering range by hand.
- Test bumper clearance at max left/right.
- Mount sensors high enough and clear from tire path.
- Use cable ties to secure wires.
- Inspect after crashes.

### Detection method

- Visual inspection.
- Full left/right steering test.
- Watch sensor readings while steering.

### Recovery behavior

- Stop run.
- Trim, reprint, or reposition bumper.
- Secure wires.

### Status

Previously observed and improved. Continue inspection.

---

## R-012 - I2C Address Conflict

### Description

Multiple VL53 sensors can have the same default address. If they start with conflicting addresses, the STM32 may fail to initialize them correctly.

### Subsystem affected

- VL53L4CD sensors
- VL53L8CX front sensor
- I2C bus
- XSHUT control
- STM32 firmware

### Causes

- sensors share default address,
- XSHUT sequence incorrect,
- firmware address assignment mismatch,
- sensor not powered during init,
- loose XSHUT wire.

### Symptoms

- one or more sensors not detected,
- distance values stuck or invalid,
- I2C bus error,
- wrong sensor reports wrong position,
- firmware hard fault or init failure.

### Impact

Medium to high.

### Mitigation

- Use XSHUT pins for controlled startup.
- Initialize sensors one at a time.
- Verify final address map in firmware.
- Label sensor cables physically.
- Add startup debug messages.
- Test each sensor individually.

### Detection method

- Print sensor initialization status.
- Run I2C scanner/debug routine.
- Check each sensor position with hand/object test.

### Recovery behavior

- Restart STM32.
- Check XSHUT wiring.
- Test sensors one-by-one.
- Correct firmware address table.

### Status

Medium. Final address map is documented: front VL53L8CX on I2C1 at 0x52 8-bit / 0x29 7-bit; side VL53L4CD sensors on I2C2 at 0x52, 0x54, and 0x56 using XSHUT pins PA5, PA7, and PB14.

---

## R-013 - Front Matrix False Corner Trigger

### Description

The front matrix may falsely detect a wall/corner too early because one cell sees an edge or irrelevant object.

### Subsystem affected

- VL53L8CX matrix
- corner detection
- Open Challenge logic
- obstacle challenge corner handling

### Causes

- one matrix cell sees side wall,
- floor reflection,
- obstacle edge,
- noisy reading,
- wrong row selected,
- valid-cell threshold too low.

### Symptoms

- robot turns before reaching corner,
- robot cuts corner too early,
- robot leaves correct lane,
- inconsistent trigger distance.

### Impact

High.

### Mitigation

- Require at least two valid in-band cells.
- Ignore known floor-band cells.
- Use median/filtered value.
- Combine with camera corner detection when available.
- Add minimum/maximum trigger distance window.

### Detection method

- Log matrix values approaching corner.
- Record trigger distance.
- Compare false triggers with matrix cell map.
- Review video frame at trigger moment.

### Recovery behavior

- Add cooldown to prevent repeated trigger.
- If trigger happens too soon during test, reduce sensitivity and require more valid cells.

### Status

Improved. Continue validation across all corner orientations.

---

## R-014 - Corner Detected Too Late

### Description

If the robot detects the corner too late, it may hit the wall or miss the turn.

### Subsystem affected

- front matrix sensor
- camera corner model
- lane-following logic
- speed control

### Causes

- front matrix filtering too strict,
- camera model misses corner line,
- robot speed too high,
- sensor mounted poorly,
- invalid matrix readings,
- timeout in sensor polling.

### Symptoms

- robot hits front wall,
- steering begins after correct turn point,
- turn radius not enough,
- repeated failure at same corner.

### Impact

High.

### Mitigation

- Tune corner trigger distance around final speed.
- Use camera + front matrix fusion.
- Reduce approach speed.
- Check front sensor alignment.
- Log trigger distance.
- Ensure matrix polling does not block too long.

### Detection method

- Mark trigger position on video.
- Measure distance to wall at trigger.
- Record speed and matrix value.

### Recovery behavior

- If front wall is closer than safe threshold, emergency turn or stop.
- Reduce speed until trigger is reliable.

### Status

Partially mitigated. Current front trigger is around ~100 cm but requires final measurement.

---

## R-015 - Over-Aggressive PDI Steering

### Description

The obstacle controller may steer too strongly when trying to pass red or green pillars.

### Subsystem affected

- obstacle strategy
- PDI controller
- steering servo
- mechanical steering
- YOLO target selection

### Causes

- high P gain,
- high derivative reaction,
- low steering clamp,
- target detected too late,
- speed too high,
- large error when pillar appears near frame edge.

### Symptoms

- full-lock steering,
- robot loses target,
- robot hits wall after avoiding pillar,
- oscillation around pillar,
- unstable recovery after pass.

### Impact

High.

### Mitigation

- Lower PDI gains.
- Clamp steering.
- Start reaction earlier.
- Reduce speed near pillars.
- Smooth detection error.
- Use target zone instead of exact center if needed.

### Detection method

- Log steering command during pillar approach.
- Review video for full-lock turns.
- Compare different PDI gain sets.

### Recovery behavior

- If steering saturates for too long, reduce command and return to lane following.
- If target lost, hold last valid detection only briefly.

### Status

Improved by softer gains and clamp, but still needs final obstacle run data.

---

## R-016 - Robot Loses Pillar Target

### Description

During avoidance, the pillar can leave the camera frame or detection can disappear for one or more frames.

### Subsystem affected

- YOLO pipeline
- obstacle controller
- target tracker
- steering logic

### Causes

- aggressive steering,
- pillar close to image edge,
- motion blur,
- temporary occlusion,
- confidence drop,
- robot speed too high.

### Symptoms

- steering command suddenly changes,
- robot stops avoiding obstacle,
- robot snaps back to lane following too early,
- robot oscillates.

### Impact

High.

### Mitigation

- Keep last valid detection for a short timeout.
- Use detection debounce.
- Reduce steering aggressiveness.
- React earlier when pillar is farther away.
- Use bounding-box area to estimate closeness.

### Detection method

- Log detection presence per frame.
- Review video with detection overlay.
- Count target-loss events.

### Recovery behavior

- Hold previous steering correction briefly.
- Return gradually to wall following after pass.
- Avoid using stale target for too long.

### Status

Open. Needs obstacle test logs.

---

## R-017 - Stop Command Not Executed

### Description

The robot may continue moving if the STOP command is missed or delayed.

### Subsystem affected

- motor command protocol
- STM32 firmware
- Jetson serial code
- Cytron motor driver
- safety behavior

### Causes

- UART frame dropped,
- serial bus busy,
- checksum failure,
- motor command wait conflict,
- STM32 command parser busy,
- software exception before stop.

### Symptoms

- robot continues moving after stop request,
- button stop delayed,
- end-of-run stop unreliable,
- robot moves during debugging.

### Impact

Very high.

### Mitigation

- Pulse STOP command multiple times.
- Use short delays between stop pulses.
- Keep emergency stop path simple.
- Test stop under sensor polling load.
- Avoid blocking code before stop.
- Consider STM32 timeout failsafe if no valid command is received.

### Detection method

- Run repeated stop tests.
- Trigger stop while front matrix is polling.
- Log stop command count and response.

### Recovery behavior

- Send repeated STOP frames.
- If software stop fails, use physical power cut during testing.
- Investigate serial log.

### Status

High. Pulsed STOP mitigation is already used.

---

## R-018 - Incorrect Motor Direction

### Description

Motor direction may be reversed compared to software expectation.

### Subsystem affected

- motor wiring
- MD10C direction input
- STM32 motor driver
- Jetson motor commands

### Causes

- motor wires reversed,
- firmware direction constant inverted,
- command mapping mismatch,
- test script uses old command mapping.

### Symptoms

- FORWARD command moves robot backward,
- REVERSE command moves robot forward,
- set-speed causes unexpected movement,
- robot leaves start area wrong direction.

### Impact

Medium to high.

### Mitigation

- Test direction before placing robot on field.
- Label motor wires.
- Keep command definitions in documentation.
- Use consistent test script.
- Confirm direction after firmware changes.

### Detection method

- Run motor command test with wheels lifted.
- Send forward/reverse and observe direction.
- Compare with encoder sign.

### Recovery behavior

- Stop immediately.
- Correct wiring or firmware direction mapping.
- Retest before autonomous run.

### Status

Medium. Previously observed start/direction issues were improved by command sequencing.

---

## R-019 - Encoder Feedback Error

### Description

Encoder readings may not match actual wheel movement.

### Subsystem affected

- motor encoder
- STM32 interrupt handling
- odometry logic
- motor degree commands

### Causes

- missed pulses,
- wrong pulses-per-revolution calculation,
- gear ratio not applied,
- A/B channel swapped,
- electrical noise,
- loose encoder wire.

### Symptoms

- degree command moves too far or too little,
- RPM value unrealistic,
- forward and reverse distance differ,
- odometry drift.

### Impact

Medium.

### Mitigation

- Validate encoder with known wheel rotations.
- Confirm quadrature direction.
- Apply correct gearbox reduction ratio.
- Use shielded or short signal wiring if needed.
- Compare commanded degrees with actual movement.

### Detection method

- Mark wheel and count rotations.
- Log encoder ticks for known movement.
- Run forward and reverse degree tests.

### Recovery behavior

- Use time/sensor-based fallback if encoder unreliable.
- Correct constants and retest.

### Status

Medium. Degree command behavior was improved after comparing Python and STM32 command formats.

---

## R-020 - Wiring Disconnect During Run

### Description

A loose cable can disconnect power, sensor, servo, motor, or communication signals.

### Subsystem affected

- all electrical subsystems

### Causes

- vibration,
- crashes,
- weak Dupont connectors,
- cable strain,
- robot motion pulling wire,
- poor cable routing.

### Symptoms

- sensor disappears,
- motor stops,
- servo stops,
- Jetson loses USB device,
- STM32 resets,
- intermittent behavior.

### Impact

Medium to high.

### Mitigation

- Use cable ties.
- Add strain relief.
- Avoid cables near wheels.
- Label connectors.
- Inspect wiring before each run.
- Use secure connectors where possible.

### Detection method

- Wiggle-test wires while system is powered.
- Check logs for intermittent disconnects.
- Inspect after every crash.

### Recovery behavior

- Stop test.
- Reconnect and secure wire.
- Retest subsystem before full run.

### Status

Medium. Continue inspection.

---

## R-021 - Repository File Too Large

### Description

Large images and videos can make the GitHub repository hard to clone or push.

### Subsystem affected

- documentation
- GitHub reproducibility
- collaboration

### Causes

- high-resolution PNG photos,
- large MP4 videos,
- uncompressed images,
- no Git LFS.

### Symptoms

- slow git operations,
- GitHub rejects files over size limit,
- repository becomes heavy,
- collaborators have trouble cloning.

### Impact

Low to medium.

### Mitigation

- Compress large images.
- Use optimized JPG for documentation display.
- Use Git LFS for large videos if needed.
- Upload videos to YouTube and link them.
- Keep original high-resolution images only when useful.

### Detection method

- Check file sizes before commit.
- Run `du -sh`.
- Watch GitHub push warnings.

### Recovery behavior

- Compress file.
- Move large file to Git LFS.
- Remove accidental large files from history if necessary.

### Status

Low. Monitor because current vehicle photos are large.

---

## R-022 - Missing Test Data

### Description

The robot may work, but documentation may lack enough test evidence to prove performance.

### Subsystem affected

- engineering journal
- test documentation
- judging reproducibility

### Causes

- runs not logged,
- videos not linked,
- lap times not recorded,
- tuning values not saved,
- success rates not calculated.

### Symptoms

- docs contain too many `Not recorded yet` values,
- impossible to compare versions,
- final behavior is not reproducible,
- judges cannot verify engineering process.

### Impact

Medium.

### Mitigation

- Use `docs/06-testing-and-tuning.md`.
- Record run ID, software version, result, lap count, time, and failure.
- Add video evidence.
- Add sensor calibration data.
- Add final tuning parameters.

### Detection method

- Review docs for `Not recorded yet`.
- Check whether each major claim has evidence.
- Ensure videos and photos are linked.

### Recovery behavior

- Run additional tests and fill missing tables.
- Add short notes even for failed runs.

### Status

Open. More test data should be added before final submission.

---

## R-023 - Parking Behavior Incomplete

### Description

The parking phase may not be fully implemented or tested.

### Subsystem affected

- obstacle challenge state machine
- sensor strategy
- motor control
- steering control
- final scoring

### Causes

- focus on lap navigation first,
- parking logic not yet tuned,
- insufficient parking test data,
- marker detection not finalized,
- final alignment strategy not complete.

### Symptoms

- robot completes laps but fails parking,
- robot stops outside parking area,
- robot touches parking markers,
- robot enters at wrong angle.

### Impact

High for Obstacle Challenge scoring.

### Mitigation

- Create dedicated parking state.
- Use side sensors to align parallel.
- Use speed reduction near parking.
- Add parking test video.
- Log final wall distance and angle.
- Add parking metrics to testing document.

### Detection method

- Run parking-only tests.
- Record final position.
- Measure parallel error.
- Count marker contact incidents.

### Recovery behavior

- If parking alignment is poor, stop safely instead of hitting markers.
- Retune entry angle and distance thresholds.

### Status

Open. Needs final implementation and evidence.

---

## R-024 - Model Not Trained for Competition Lighting

### Description

The YOLO model may perform well during development but fail in the actual competition environment if lighting or camera angle differs.

### Subsystem affected

- YOLO model
- dataset
- camera calibration
- obstacle behavior

### Causes

- small dataset,
- limited lighting variety,
- no examples from final field setup,
- different camera exposure,
- changed camera mount angle,
- model trained only on clean/centered pillars.

### Symptoms

- confidence drops in competition lighting,
- false positives increase,
- green/red confusion,
- late detection,
- bounding boxes unstable.

### Impact

High.

### Mitigation

- Capture training images from final robot camera.
- Include different distances, angles, and light conditions.
- Include partial occlusion and edge-of-frame examples.
- Test with final camera mount.
- Add validation videos with overlay.
- Tune confidence thresholds after final mounting.

### Detection method

- Run model on recorded competition-like footage.
- Compare detections across light conditions.
- Measure true/false positive rate.

### Recovery behavior

- Lower speed if detection uncertainty increases.
- Fall back to conservative wall following if no valid pillar exists.

### Status

Open. Needs final dataset/model documentation.

---

## R-025 - Sensor Calibration Drift After Mechanical Changes

### Description

When sensors are moved or bumper geometry changes, previous calibration values may no longer be valid.

### Subsystem affected

- VL53L4CD sensors
- VL53L8CX front sensor
- wall-following controller
- corner trigger
- obstacle distance logic

### Causes

- bumper redesign,
- sensor remounting,
- sensor angle shift after crash,
- screw loosening,
- new 3D-printed bracket,
- height change.

### Symptoms

- robot follows wall at wrong distance,
- front trigger distance changes,
- left/right readings not symmetric,
- obstacle response starts too late or early,
- previous tuning no longer works.

### Impact

High.

### Mitigation

- Recalibrate after mechanical changes.
- Mark final sensor positions.
- Tighten mounts.
- Use fixed-distance calibration procedure.
- Add calibration values to docs.
- Do not tune software until mechanical position is stable.

### Detection method

- Compare readings at known distances.
- Check before/after mechanical modifications.
- Record calibration table.

### Recovery behavior

- Re-run sensor calibration.
- Update thresholds and documentation.

### Status

High. Continue calibration after each sensor/bumper change.

---

## 7. Risk Mitigation Checklist Before Each Test Session

Use this checklist before running the robot on the field.

### Mechanical

- [ ] Wheels are clean.
- [ ] Steering moves left and right without binding.
- [ ] Servo horn and linkage screws are tight.
- [ ] Front bumper does not touch tires.
- [ ] Sensor mounts are fixed and not loose.
- [ ] No cables touch wheels or steering linkage.

### Power

- [ ] Motor battery charged.
- [ ] Jetson/UPS battery charged.
- [ ] Battery voltage recorded.
- [ ] Power connectors secure.
- [ ] No signs of overheating.
- [ ] Servo power stable.

### Sensors

- [ ] VL53L4CD sensors return valid values.
- [ ] VL53L8CX front matrix returns valid matrix.
- [ ] No side sensor stuck at `-1`.
- [ ] I2C sensors initialize successfully.
- [ ] Sensor readings match approximate real distances.

### Vision

- [ ] Camera starts correctly.
- [ ] YOLO detects red pillar.
- [ ] YOLO detects green pillar.
- [ ] Detection confidence is reasonable.
- [ ] Lighting is similar to expected run condition.
- [ ] Camera lens is clean.

### Communication

- [ ] STM32 serial port opens.
- [ ] Sensor command returns expected data.
- [ ] Motor forward command works.
- [ ] Motor stop command works.
- [ ] STOP command tested multiple times.
- [ ] No serial timeout before run.

### Software

- [ ] Correct challenge script selected.
- [ ] Correct model file selected.
- [ ] Correct serial ports selected.
- [ ] Correct speed setting selected.
- [ ] Logs enabled if testing.
- [ ] Emergency stop method ready.

---

## 8. Competition-Day Risk Checklist

Before the official run:

1. Charge all batteries.
2. Measure voltage.
3. Clean wheels.
4. Clean camera lens.
5. Check front bumper clearance.
6. Check steering center.
7. Check all sensor readings.
8. Check YOLO red/green detection.
9. Run motor forward/stop test.
10. Run steering left/right/center test.
11. Verify correct challenge mode.
12. Verify final speed setting.
13. Verify video/documentation evidence if needed.
14. Keep physical power-off method ready during testing.

---

## 9. Safe-State Strategy

A safe state is the behavior the robot should enter when it cannot trust its inputs or outputs.

### Safe-state triggers

| Trigger | Safe response |
|---|---|
| Repeated UART timeout | Send STOP repeatedly |
| Too many invalid sensors | Slow down or stop |
| Camera lost | Continue wall following only if safe; otherwise stop |
| Jetson exception | Stop motor if possible |
| Battery low | Stop testing |
| Servo stuck | Stop run |
| Unknown state-machine condition | Stop or return to straight-drive safe behavior |

### Minimum safe command

```text
STOP -> STOP -> STOP
```

Critical stop commands should be pulsed because one serial frame may be lost during heavy communication.

---

## 10. Risk Ownership

| Risk area | Owner / responsible focus |
|---|---|
| Mechanical risks | Team mechanical build and inspection |
| Power risks | Wiring, battery, and current validation |
| Sensor risks | STM32 firmware and calibration testing |
| Vision risks | YOLO model and Jetson camera pipeline |
| Communication risks | Jetson serial code and STM32 protocol |
| Strategy risks | Challenge state machine and tuning |
| Documentation risks | GitHub README, docs, journal, videos, photos |

---

## 11. Test Evidence Needed for Final Risk Closure

The following evidence is needed to close or reduce the highest risks:

| Risk | Evidence needed |
|---|---|
| Glare / lighting | Video or screenshots showing YOLO under different lighting |
| Bad pillar detection | Detection statistics for red and green pillars |
| Sensor noise | Calibration table and invalid-reading rate |
| UART timeout | Serial timeout count during full runs |
| Motor blocking | Camera FPS with motor commands active |
| Weak battery | Voltage before/after 3-minute run |
| Stop command failure | Repeated STOP test results |
| Front matrix false trigger | Matrix logs during corner approach |
| Parking incomplete | Parking test video and success table |
| Steering jitter | Servo current or observed stability test |

---

## 12. Change Log

| Date | Change | Notes |
|---|---|---|
| Not recorded yet | Initial risk register created | Includes glare, sensor noise, UART timeout, motor blocking, weak battery, and bad pillar detection |
| Not recorded yet | Add final test evidence | Fill after more field testing |
| Not recorded yet | Update probability/impact after competition-like tests | Replace estimated scores with measured experience |

---

## 13. Conclusion

The most important risks for ARBIBOT are not isolated component failures. They are system interaction failures:

- the motor command can block the camera loop,
- a weak battery can create sensor and steering problems,
- bad lighting can create bad obstacle decisions,
- a noisy sensor can create a wrong turn,
- a dropped UART frame can prevent a stop command,
- aggressive steering can cause the camera to lose the pillar target.

The robot has already improved by addressing several of these risks: ToF sensors replaced ultrasonic sensors, wider wheels replaced thinner slipping wheels, the front matrix logic was filtered, right-front/right-rear heading correction improved wall following, and critical commands are pulsed to reduce serial failure impact.

The remaining goal is to keep converting risks into test evidence. Each failure mode should have a mitigation, a detection method, and a test result proving whether the mitigation is effective.

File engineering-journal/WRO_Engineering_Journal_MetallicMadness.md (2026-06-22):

# Engineering Journal - MetallicMadness / ARBIBOT

**Competition:** WRO 2026 Future Engineers - Self-Driving Cars  
**Team:** MetallicMadness  
**Robot:** ARBIBOT  
**Organization:** Universidad Metropolitana, Caracas  
**Document status:** Draft 1 - prepared from current team information. Replace `[TODO]` fields before final submission.

---

## 1. Introduction

ARBIBOT is a four-wheel autonomous vehicle designed for the WRO Future Engineers Self-Driving Cars challenge. The robot is built around a split-control architecture: an NVIDIA Jetson Orin Nano performs high-level perception and navigation decisions, while an STM32F411 microcontroller handles low-level peripheral control, distance sensors, motor control, encoder feedback, and serial command execution.

The design objective is to build a stable self-driving robot able to complete the Open Challenge and the Obstacle Challenge using sensor fusion between computer vision, ToF distance sensors, motor feedback, and deterministic control logic. The engineering work focuses on reliability under competition constraints: limited vehicle size, autonomous operation, random field configuration, lighting variation, sensor noise, power stability, and fast recovery from edge cases.

This journal is organized to match the WRO engineering documentation rubric: mobility and mechanical design, power and sensor architecture, software and obstacle strategy, systems thinking, reproducibility, and testing.

---

## 2. Team Overview

| Role | Name | Summary |
|---|---|---|
| Student | Daniel Jose Denis Castillo | Electrical Engineering student at Universidad Metropolitana in Caracas. Strong interest in electronics, robotics, Python, AI models, and technical problem solving. |
| Student | Douglas Gabriel Ordaz Yanez | Electrical Engineering and Computer Engineering student at Universidad Metropolitana in Caracas. Strong interest in software development, coding logic, and game programming. |
| Tutor / Coach | Daniel Jose Denis Rodriguez | Electrical Engineer from Universidad Metropolitana with more than 25 years of experience in software engineering, telecommunications, AI, cybersecurity, embedded systems, and technology leadership. |

---

## 3. Design Goals and WRO Constraints

The robot was designed around the following WRO-related engineering constraints:

| Constraint / Requirement | ARBIBOT design response |
|---|---|
| Four-wheel vehicle, not differential drive | Rear-wheel drive with a front steering actuator. The two rear wheels are mechanically linked through the drive system. |
| One steering actuator | MG996R servo drives a pushrod/tie-rod steering linkage. |
| Autonomous operation | Jetson and STM32 run onboard; no wireless control is used during a round. |
| Maximum dimensions | Current dimensions: 25 cm length x 15.6 cm width x 18 cm height. |
| Maximum weight | Current measured weight: 1.35 kg. |
| Challenge time | Estimated runtime is 20-30 minutes, comfortably above the 3-minute round requirement. |
| Randomized field | Software uses sensor fusion and state logic instead of hard-coded field layouts. |

---

## 4. Overall System Architecture

ARBIBOT uses a two-controller architecture:

1. **NVIDIA Jetson Orin Nano:** high-level perception, AI inference, camera processing, navigation decisions, YOLO-based pillar and line/corner detection, and command generation.
2. **STM32F411 Black Pill:** low-level real-time controller for ToF sensors, IMU, motor driver, encoder feedback, and DD-UART command handling.

The Jetson sends compact commands to the STM32 through a custom binary USART protocol. The STM32 executes deterministic peripheral operations and returns sensor values or command acknowledgements. This separation keeps the Jetson focused on perception and planning while the microcontroller handles real-time I/O.

### System block overview

```text
Camera + YOLO + navigation logic
        |
        v
NVIDIA Jetson Orin Nano
        |
        | USB serial / DD-UART protocol
        v
STM32F411 Black Pill
        |------------------- ToF sensors / IMU
        |------------------- Cytron MD10C motor driver
        |------------------- Encoder feedback
        |------------------- Sensor address/reset control

Separate power domains:
- Motor power: 3S Li-ion pack + BMS 3S 20A -> Cytron MD10C -> DC motor
- Jetson/logic power: Waveshare UPS -> Jetson + camera + Pololu servo controller
```

STM32 wiring diagram

**Figure 1. STM32F411 wiring and peripheral integration diagram.**

---

## 5. Mobility and Mechanical Design

### 5.1 Mechanical summary

| Item | Current design |
|---|---|
| Chassis | 3D printed chassis |
| Vehicle length | 25 cm |
| Vehicle width | 15.6 cm |
| Vehicle height | 18 cm |
| Weight | 1.35 kg |
| Wheelbase | 13.9 cm |
| Track width | [TODO: measure distance between left and right wheels] |
| Drive configuration | Rear-wheel drive |
| Steering | Servo-actuated pushrod steering with tie-rod linkage |
| Steering servo | MG996R, 5 V, approx. 9.4 kg-cm at 4.8 V |
| Drive motor | JGY-370B 12 V DC worm gear motor with encoder, 150 RPM |

### 5.2 Steering mechanism

The vehicle uses a **servo-actuated front steering mechanism**. The steering servo moves a control arm connected to a pushrod. The pushrod actuates one front steering knuckle, and both front wheels are mechanically connected by a tie rod. Therefore, the motion of one wheel is transferred to the other front wheel, producing synchronized front steering using a single steering actuator.

The mechanism is best described as a **custom servo-driven pushrod and tie-rod steering linkage**. It is Ackermann-inspired, but it should not be claimed as a validated Ackermann geometry until the inner and outer wheel angles are measured during steering.

Steering linkage

**Figure 2. Steering linkage close-up showing pushrod and tie-rod connection.**

### 5.3 Drive motor and encoder

ARBIBOT uses a JGY-370B 12 V mini worm gear DC motor with encoder feedback. The motor is a double-shaft DC gear motor with hall-coded tachymetry feedback and 150 RPM nominal no-load speed. The selected motor includes metal gears and self-locking behavior, which improves vehicle holding behavior when power is removed.

Encoder characteristics provided by the team:

| Encoder parameter | Value |
|---|---|
| Hall elements | 2 Hall sensors |
| Output type | AB-phase square wave |
| Basic pulse count | 11 PPR at motor shaft |
| Encoder voltage | 3.3 V / 5 V |
| Response frequency | 100 kHz |
| Firmware use | Distance by degrees and RPM estimation |

Motor encoder wiring

**Figure 3. Encoder wiring reference for the JGY-370 motor.**

### 5.4 Mechanical iterations and lessons learned

| Design issue tested | Problem observed | Final decision / improvement |
|---|---|---|
| Motor without encoder | No direct feedback for speed or distance estimation. | Replaced with encoded JGY-370 motor to support RPM and move-by-degrees commands. |
| Single-shaft motor with gearbox and linked rear wheels | Significant torque transfer problems between gearbox gear and wheel gear. | Moved to a more reliable double-shaft gear motor approach. |
| Thin wheels | Wheels slid on the track, reducing stability and control. | Thicker / higher-grip wheels were preferred. |
| Ultrasonic distance sensors | Lower precision and less stable behavior for this application. | Replaced by ST VL53 laser ToF sensors. |
| Early bumper design | Bumper rubbed against the tire during turns and sensors were mounted too low. | Bumper geometry and sensor mounting height were revised. |
| Steering linkage dimensions | Initial servo arm and linkage dimensions limited steering range and alignment. | Servo arm, rods, and alignment screw were adjusted to improve turning range and front-wheel alignment. |

---

## 6. Power and Sensor Architecture

### 6.1 Power architecture

ARBIBOT uses separated power paths for the motor system and the Jetson/logic system. This is important because the drive motor and steering servo create current peaks that can cause voltage dips, sensor noise, or serial communication faults if not isolated correctly.

| Power domain | Components powered | Source / path |
|---|---|---|
| Motor power | Cytron MD10C and DC drive motor | 3 x 18650 Li-ion cells through BMS 3S 20A |
| STM32 power | STM32F411 low-level controller | USB/TTL 5 V supply |
| Jetson / vision power | Jetson Orin Nano and CSI camera | Waveshare UPS module, Jetson powered at 12 V |
| Steering power | Pololu servo controller and MG996R servo | Powered from Waveshare UPS system |

BMS module

**Figure 4. BMS 3S 20 A module used for motor battery protection.**

Waveshare UPS module

**Figure 5. Waveshare UPS module used for the Jetson power domain.**

### 6.2 Estimated power budget

The following table is an engineering estimate based on currently available component information. Final documentation should replace estimates with measurements from a USB power meter, inline wattmeter, or bench supply.

| Component | Voltage | Typical current | Peak current | Typical power | Peak power | Notes |
|---|---:|---:|---:|---:|---:|---|
| Jetson Orin Nano | 12 V | approx. 2.1 A | approx. 3.3 A | 25 W | 40 W | Depends on AI workload and power mode. |
| STM32F411 | 3.3/5 V | approx. 10 mA | [TODO] | <0.1 W | [TODO] | Peripherals and clocks affect total. |
| MG996R steering servo | 5 V | 0.5-0.9 A under load | 1.5-2.5 A stall | 2.5-4.5 W | 7.5-12.5 W | Steering peaks are short but important. |
| JGY-370B drive motor | 12 V | 0.2-0.3 A rated load | 1.3-2.0 A stall | 2.4-3.6 W | 15.6-24 W | Peak during acceleration or stalled wheels. |
| VL53L4CD sensors x3 | 3.3 V | 45-75 mA total | [TODO] | 0.15-0.25 W | [TODO] | 15-25 mA each during active ranging. |
| VL53L8CH front matrix sensor | 3.3 V | [TODO] | [TODO] | [TODO] | [TODO] | Measure during continuous matrix ranging. |
| Camera IMX477 | Jetson CSI | [TODO] | [TODO] | [TODO] | [TODO] | Powered directly from Jetson CSI connector. |
| CP2102 USB-TTL | 5 V | [TODO] | [TODO] | [TODO] | [TODO] | Used for serial interface / debugging. |

**Engineering interpretation:** the average consumption is dominated by the Jetson, while the motor and steering servo dominate peak current events. The split power architecture reduces the chance that motor current spikes will reset the Jetson or corrupt sensor readings. Estimated runtime is 20-30 minutes, which is above the 3-minute challenge duration, but final validation should include voltage sag testing during acceleration and repeated steering.

### 6.3 Sensor architecture

| Sensor | Quantity | Placement | Main use |
|---|---:|---|---|
| VL53L4CD | 3 | Front-right bumper, rear-right/middle between wheels, left/front bumper | Wall following, side correction, obstacle distance, parking support |
| VL53L8CH | 1 | Center front bumper | Front distance matrix and obstacle/wall perception |
| IMU | 1 | On low-level controller system | Gyroscope and accelerometer telemetry |
| IMX477 camera | 1 | Front/top camera mount | YOLO object detection, line/corner detection |

The right-side VL53L4CD pair is used to estimate heading relative to the wall. The difference between the right-front and right-rear readings indicates whether the robot is angled toward or away from the wall, enabling a heading correction term in the lane controller.

### 6.4 I2C addressing and reset control

| Sensor | Firmware address notation | XSHUT / reset pin |
|---|---:|---|
| Left VL53L4CD | 0x52H | PA5 |
| Right-front VL53L4CD | 0x54H | PA7 |
| Right-rear VL53L4CD | 0x56H | PB14 |
| Front VL53L8CH | 0x52H | [TODO: confirm bus and reset handling] |

**Note:** final documentation should clarify whether addresses are written as 7-bit or 8-bit I2C addresses, and whether the VL53L8CH is isolated on a separate I2C bus. This avoids confusion because several ST ToF sensors share default address conventions.

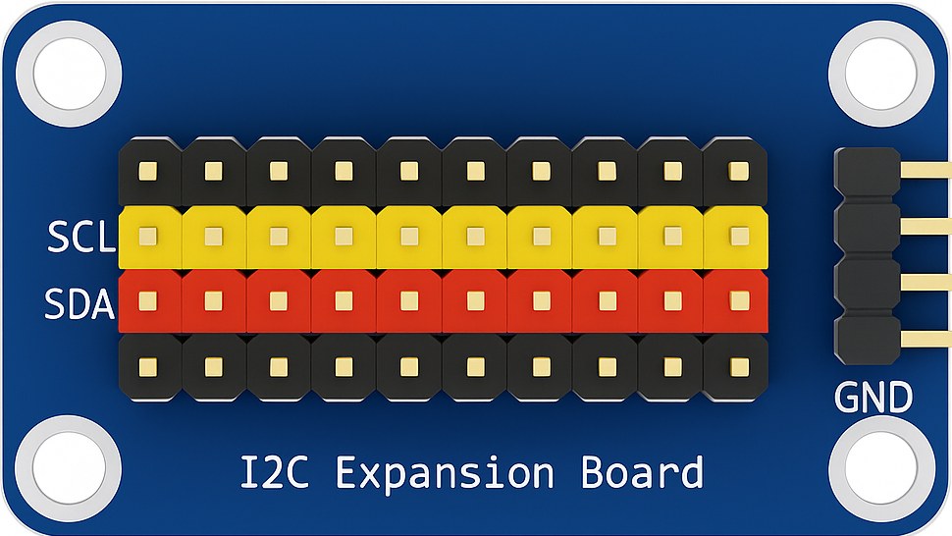
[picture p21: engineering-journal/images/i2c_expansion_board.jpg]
I2C expansion board


**Figure 6. I2C expansion board used to simplify shared SDA/SCL and power distribution.**

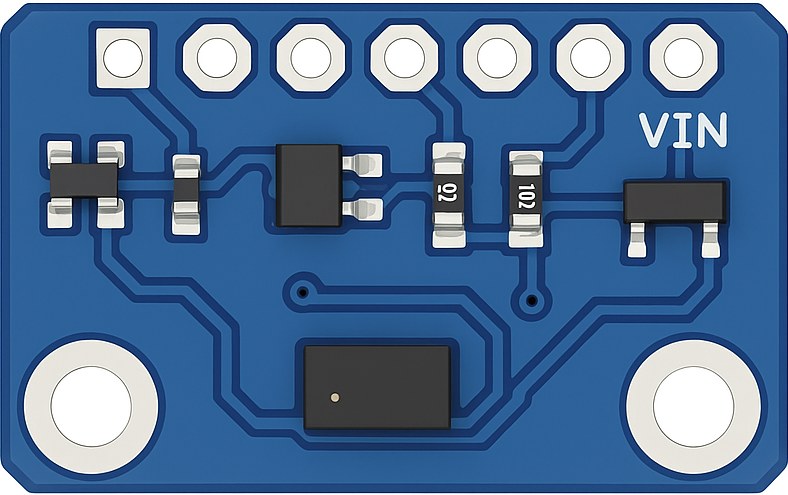
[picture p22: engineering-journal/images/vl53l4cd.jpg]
VL53L4CD


**Figure 7. VL53L4CD ToF sensor module used for side/wall distance readings.**

VL53L8CH

**Figure 8. VL53L8CH front matrix ToF sensor module used for front distance perception.**

### 6.5 Sensor calibration

Distance calibration is performed at fixed references from 120 cm down to 10 cm: 120, 110, 100, 90, 80, 70, 60, 50, 40, 30, 20, and 10 cm. A Python tool reads all sensors at each position while the car is moved through known distances. This process allows the team to detect sensor offsets, dead zones, and unstable ranges.

---

## 7. Software Architecture and Obstacle Strategy

### 7.1 Jetson software responsibilities

The Jetson Orin Nano runs the high-level autonomous driving stack:

- CSI camera capture through GStreamer (`nvarguscamerasrc`) into OpenCV at 1280 x 720.
- Ultralytics YOLO inference using custom trained weights.
- Line/corner model for Open Challenge support.
- Pillar model for Obstacle Challenge detection: `Green_Pillar`, `Red_Pillar`.
- Lane/corner logic using camera detections, side ToF heading, and front ToF matrix data.
- Navigation decisions through PID/PDI control and threshold state logic.
- DD-UART command generation to the STM32.

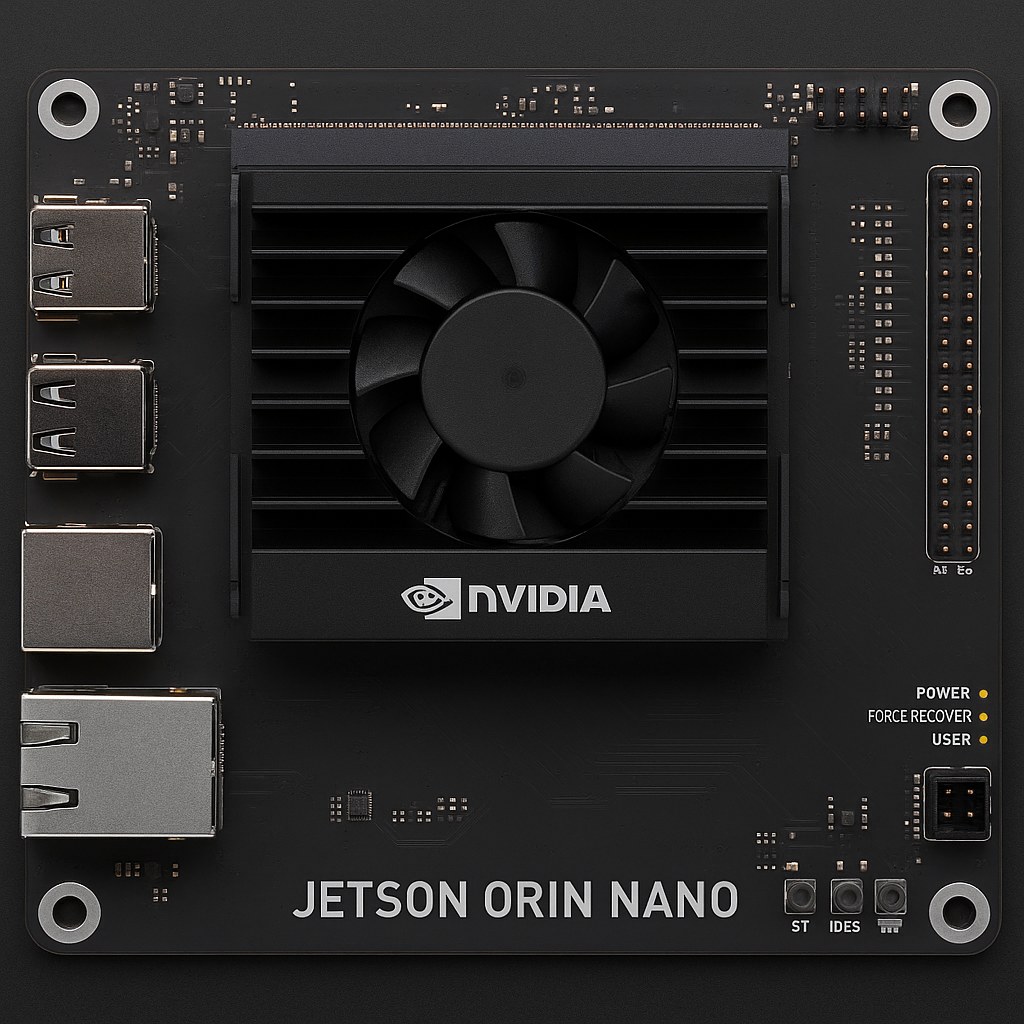
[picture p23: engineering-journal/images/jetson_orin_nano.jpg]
Jetson Orin Nano


**Figure 9. NVIDIA Jetson Orin Nano selected for AI inference and high-level navigation.**

### 7.2 STM32 software responsibilities

The STM32F411 runs the low-level control and sensor acquisition stack:

- Polls VL53L4CD side sensors.
- Polls front VL53L7CX/L8 8x8 to 4x4 matrix data.
- Reads IMU gyro/accelerometer data.
- Controls the Cytron MD10C using PWM and direction pins.
- Reads quadrature encoder signals using EXTI interrupts.
- Executes continuous motor commands, stop commands, set-speed commands, and move-by-degrees commands.
- Parses DD-UART frames, validates checksum, dispatches commands, and returns response frames.

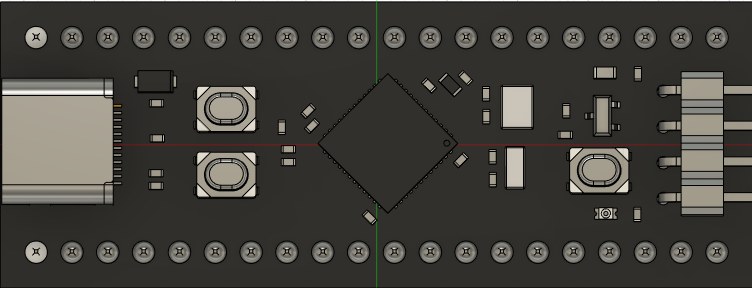
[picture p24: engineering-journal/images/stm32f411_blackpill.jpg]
STM32F411 Black Pill


**Figure 10. STM32F411 Black Pill used as low-level peripheral controller.**

Cytron MD10C motor driver

**Figure 11. Cytron MD10C motor driver used to control the 12 V DC drive motor.**

### 7.3 Main Jetson modules

| File | Role |
|---|---|
| `main_challenge_01_v4.py` | Open Challenge: camera-corner + heading wall-follow + front-matrix corner trigger. |
| `main_challenge_02.py` | Obstacle Challenge: pillar YOLO + PDI pass-side steering. |
| `turn_models.py` | CornerDetector line YOLO and result drawing. |
| `Pillar_recognition.py` | YOLO result to detection object: color, zone, area, nearest-pillar choice. |
| `pillar_counter.py` | Debounced enter/exit counting per pillar color. |
| `pid_line_follower.py` | PID lane controller: difference and single-wall modes. |
| `sensor_distance_v3.py` | Side-ToF + front-matrix reader/parser; extracts front barrier distance. |
| `motor_driver.py` | DD-UART motor command client. |
| `servo_controller.py` | Steering servo control over separate serial interface. |
| `color_tuning.py` | Per-camera color correction for detection models. |

### 7.4 Main STM32 modules

| File | Role |
|---|---|
| `serial_dd_protocol.c/.h` | DD-UART parsing, checksum validation, command dispatch, response. |
| `motor_drv.c/.h` | PWM, direction, set-speed, move-by-degrees, encoder count, RPM. |
| `sensor_vl53l4cd.c` | Side ToF distance sensors. |
| `sensor_vl53l7ch.c` | Front VL53L7CX/L8 4x4 matrix ToF. |
| `sensor_imu.c` | IMU gyro/accelerometer. |
| `platform.c / platform2.c` | I2C platform layer for ToF sensors. |
| `main.c` | Command dispatch and main loop. |

### 7.5 State machine

```text
WAITING_FOR_START
        |
        v
FIRST_SECTOR
        |
        v
STRAIGHT_DRIVE <------------------+
   |                               |
   | pillar detected               | corner completed
   v                               |
OBSTACLE_HANDLING                  |
   |                               |
   +----> return to STRAIGHT_DRIVE |
                                   |
   | corner detected               |
   v                               |
CORNERING -------------------------+
        |
        v
FINISH / STOP
```

### 7.6 Navigation and obstacle strategy

**Pillar detection:** The pillar YOLO model returns a class and bounding box. The class identifies the color, the horizontal location determines whether the object is in the left, center, or right image zone, and the bounding-box area estimates proximity. The largest area is treated as the nearest relevant pillar.

**Obstacle rule behavior:** Red pillars are passed on the right side of the lane. Green pillars are passed on the left side of the lane. The robot computes the horizontal gap between the required pass-side boundary and the pillar edge, then uses a PDI controller to keep the pillar in the correct third of the image.

**Corner detection:** Corner detection fuses three cues: line/corner detections from the camera, front ToF matrix distance to the wall, and a right-wall-collapse fallback. The front matrix trigger fires around 1 m when enough matrix cells confirm a front barrier.

**Lane holding:** The two right-side ToF sensors are used as a heading wall follower. The controller uses both distance error and the difference between right-front and right-rear sensor readings. This prevents the robot from driving parallel errors into the wall.

**Encoder use:** The encoder is used for move-by-degrees distance control and RPM estimation. Turns are currently timed open-loop and triggered by camera + ToF cues rather than encoder angle.

### 7.7 DD-UART protocol

Frame format:

```text
$ LEN(2 bytes, big-endian) CMD(2 bytes, big-endian) DATA(0..n) CHK(1 byte) \n
CHK = XOR checksum over LEN + CMD + DATA
```

| CMD | Name | Payload | Response |
|---:|---|---|---|
| `0x0001` | READ_GYRO | None | IMU gyro |
| `0x0002` | READ_ACCEL | None | IMU accel |
| `0x0003` | READ_FRONT | None | Front matrix text |
| `0x0004` | FORWARD continuous | None | `Forward` |
| `0x0005` | REVERSE continuous | None | `Reverse` |
| `0x0101` | FORWARD by degrees | uint16 LE degrees | ack |
| `0x0102` | REVERSE by degrees | uint16 LE degrees | ack |
| `0x0103` | STOP | None | `Stopped` |
| `0x0104` | SET SPEED | uint8 percent | `Speed updated` |
| `0x0105` | READ SIDES | None | RF, RR, LEFT distances |

Common command sequence: set speed (`0x0104`), forward (`0x0004`), stop (`0x0103`), read side sensors (`0x0105`), and read front matrix (`0x0003`).

---

## 8. Vision System and YOLO Training

The vision system uses a Mini 12.3 MP HQ camera compatible with the NVIDIA Jetson platform. The camera is based on the IMX477 sensor and uses an M12 mount lens. The camera feeds the Jetson through the MIPI CSI-2 interface.

Two YOLO models are used:

| Model | Purpose | Classes / outputs |
|---|---|---|
| Pillar model | Obstacle Challenge traffic sign detection | `Green_Pillar`, `Red_Pillar` |
| Line/corner model | Open Challenge corner/line support | [TODO: exact class names for blue/orange line model] |

YOLO was selected instead of simple color thresholding because lighting conditions, glare, shadows, and partial occlusion can shift raw color values. A trained detector can localize and classify pillars more robustly than fixed HSV thresholds. The software still uses color correction and confidence thresholds to reduce false positives.

| Vision parameter | Current value |
|---|---|
| YOLO version | [TODO: confirm YOLOv8, YOLO11, or other] |
| Weights | `Models/best_model_1.pt` and line/corner weights |
| Pillar confidence threshold | 0.30 |
| Corner line confidence threshold | 0.48 |
| Dataset size | [TODO: number of labeled images per model] |
| Annotation tool | [TODO: Roboflow, CVAT, labelImg, etc.] |
| Training environment | [TODO: PC GPU, Google Colab, Jetson, etc.] |
| Jetson inference speed | [TODO: FPS or ms/frame measured on robot] |

---

## 9. Systems Thinking and Engineering Decisions

### 9.1 Major design decisions

| Decision | Alternatives considered | Reason for final choice |
|---|---|---|
| Jetson + STM32 split architecture | Single controller only | Jetson is strong for AI inference; STM32 is better for deterministic I/O and motor/sensor timing. |
| ToF laser sensors instead of ultrasonic | Ultrasonic modules | ToF sensors provided better precision and more stable short-range readings for wall following and parking. |
| Encoded DC motor | Motor without encoder | Encoder enables RPM estimation and move-by-degrees control. |
| Two right-side sensors for heading | Single distance sensor | Two readings reveal angle relative to wall; one reading only gives distance. |
| Separate motor and Jetson power paths | Shared battery | Separate domains reduce brownouts, resets, and sensor/serial noise from motor peaks. |
| YOLO instead of pure color threshold | HSV thresholding | YOLO is more robust to lighting, glare, and partial occlusion. |
| Pulsed critical serial commands | Single command transmission | Shared serial bus can drop frames during heavy sensor traffic; repeated start/stop commands improve reliability. |

### 9.2 Risk register

| Risk / failure mode | Cause | Mitigation |
|---|---|---|
| Jetson brownout | AI load plus peripheral current peaks | Separate UPS power path for Jetson. |
| Motor noise affects sensors | High current switching and common ground noise | Separated power paths and common ground discipline. |
| Serial frame lost | Shared sensor/motor serial bus busy | Sensor thread owns reads; motor commands are fire-and-forget and critical commands are pulsed. |
| Lane wandering | Distance-only wall control ignores heading | Added right-front minus right-rear heading term. |
| False corner trigger | Single ToF matrix cell sees an edge/wall artifact | Require at least two in-band cells before firing. |
| Late corner trigger | Floor cells distort matrix distance | Exclude floor-band cells and use row-specific barrier logic. |
| Pillar over-steering | High PDI gain and late reaction | Soften gains, lower steering clamp, react earlier. |
| Tire slip | Thin wheels with low grip | Use wider / higher-grip wheels. |

---

## 10. Testing, Failures, and Improvements

### 10.1 Software version evolution

| Version | Description |
|---|---|
| v1 - `main_challenge_01.py` | Camera corner detection + open-loop center steering. |
| v2 - `main_challenge_01_v2.py` | Added PID wall-following and sensor/front-ToF corner fallbacks. |
| v3 - `main_challenge_01_v3.py` | Two-right-sensor follow + new VL53L8 4x4 matrix; abandoned because it became unstable and over-complex. |
| v4 - current Open Challenge | v2 proven base + new firmware sensors + 4x4 front-matrix trigger + RF-RR heading wall follower. |
| `main_challenge_02.py` | Current Obstacle Challenge: pillar YOLO + PDI pass-side steering on reliable v4 scaffolding. |

### 10.2 Problems and fixes

| Problem | Root cause | Fix |
|---|---|---|
| Turned too late and hit front wall | Front sensor swap to VL53L8 4x4; floor cells in matrix row pulled distance estimate down. | Excluded floor-band cells and used row-specific barrier distance. |
| Turned too soon | Lone matrix cell saw outer-wall corner. | Require at least two in-band cells to trigger a turn. |
| Car would not start or ran in reverse | Set-speed caused idle reverse behavior and single frame could drop on busy serial bus. | Send forward first, interleave speed, and pulse commands several times. |
| Stop button did not always stop robot | Stop frame dropped during matrix scan. | Pulse stop command. |
| Side sensors read `-1` | Parser mismatch with new firmware; later YOLO load starved serial thread. | Updated parser and avoided heavy matrix polling until needed. |
| Lane wandered wall-to-wall | Distance-only PID was blind to vehicle heading. | Added RF-RR heading term to keep car parallel. |
| Pillar steering full-lock / lost target | PDI gains too high and action started too close to pillar. | Reduced gains, lowered steering clamp, and started reaction earlier. |

### 10.3 Current performance notes

| Metric | Current value |
|---|---|
| Best lap time | [TODO] |
| Average lap time | [TODO] |
| Open Challenge success rate | [TODO] |
| Obstacle Challenge success rate | [TODO] |
| Parking success rate | [TODO] |
| Observed progress | Open Challenge reached approximately 2.5 of 3 laps before lane-keeping failure; single clean laps achieved repeatedly. |
| Front matrix trigger | Fires reliably around 100 cm based on current tests. |

---

## 11. Reproducibility and Build Instructions

This section must be completed before final submission so another team or judge can rebuild and run the robot with reasonable effort.

### 11.1 Hardware assembly overview

1. 3D print or manufacture the chassis and sensor/board mounts.
2. Install rear drive motor and mechanically connect rear wheels through the drive system.
3. Install front steering knuckles, tie rod, steering servo, servo horn, and pushrod.
4. Mount Jetson Orin Nano and UPS module.
5. Mount STM32F411 and connect sensors, motor driver, and encoder.
6. Mount the front bumper and install VL53L4CD / VL53L8CH sensors at the final tested height.
7. Mount the IMX477 camera and adjust its pitch and field of view.
8. Wire the motor battery through the BMS to the Cytron MD10C.
9. Wire logic power and grounds, ensuring a shared ground reference where required.
10. Run sensor calibration and steering-center calibration before test laps.

### 11.2 STM32 flashing

[TODO: add exact flashing instructions]

Suggested content to add:

```bash
# Example only - replace with your exact workflow
# 1. Open STM32CubeIDE project
# 2. Select STM32F411CEU6 target
# 3. Build firmware
# 4. Flash through ST-Link or USB bootloader
```

### 11.3 Jetson setup

[TODO: add exact OS, Python version, and installation steps]

Suggested content to add:

```bash
# Example only - replace with exact commands
sudo apt update
python3 -m venv .venv
source .venv/bin/activate
pip install -r requirements.txt
```

### 11.4 Run procedure

1. Place the robot in the starting zone completely switched off.
2. Power on the robot using the allowed power switch.
3. Wait for the software to enter `WAITING_FOR_START` state.
4. After the judge command, press the single start button.
5. The robot begins autonomous operation.
6. The robot stops autonomously at the end of the challenge or when the stop condition is met.

---

## 12. Media and Evidence Checklist

| Item | Status |
|---|---|
| Vehicle front photo | [TODO] |
| Vehicle rear photo | [TODO] |
| Vehicle left side photo | [TODO] |
| Vehicle right side photo | [TODO] |
| Vehicle top photo | [TODO] |
| Vehicle bottom photo | [TODO] |
| Close-up of sensor mounts | [TODO] |
| Close-up of steering mechanism | Available: steering close-up photo |
| Close-up of motor + encoder installation | [TODO] |
| Team photo | [TODO] |
| Open Challenge video, minimum 30 seconds | [TODO: YouTube link] |
| Obstacle Challenge video, minimum 30 seconds | [TODO: YouTube link] |

---

## 13. Appendix A - Component Image References

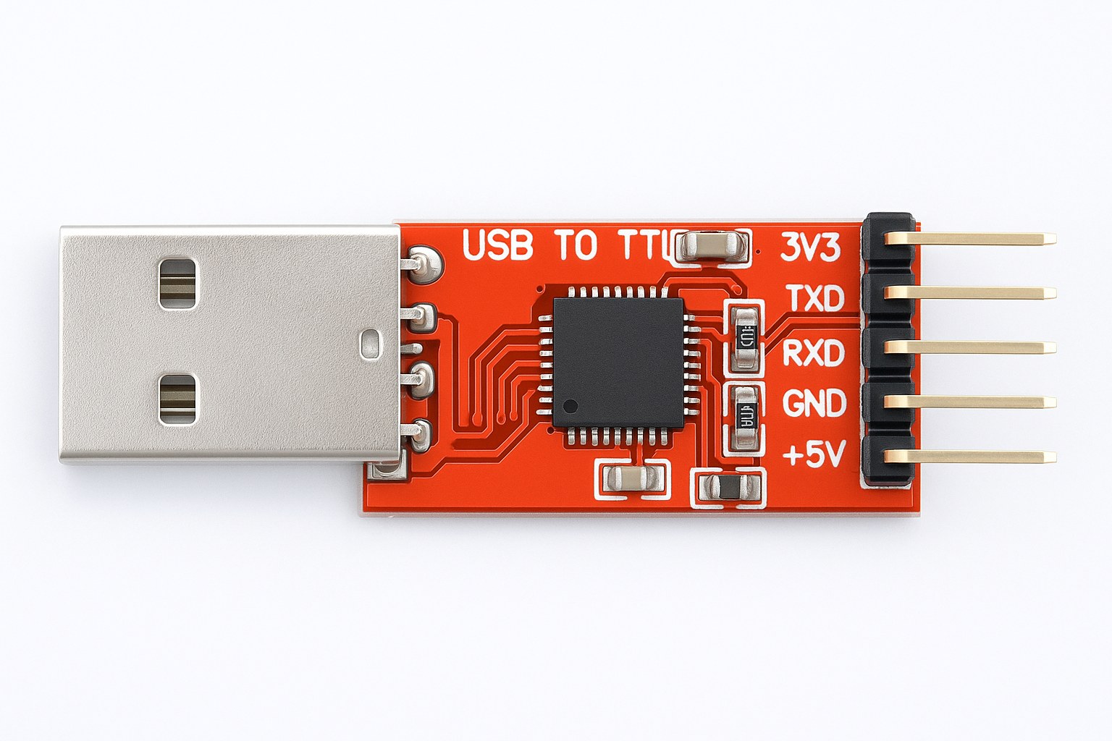
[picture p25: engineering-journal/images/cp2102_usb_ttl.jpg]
CP2102 USB-TTL


**Figure A1. CP2102 USB-TTL module used for serial communication/debugging.**

Pololu servo controller

**Figure A2. Pololu servo controller used for steering servo control.**

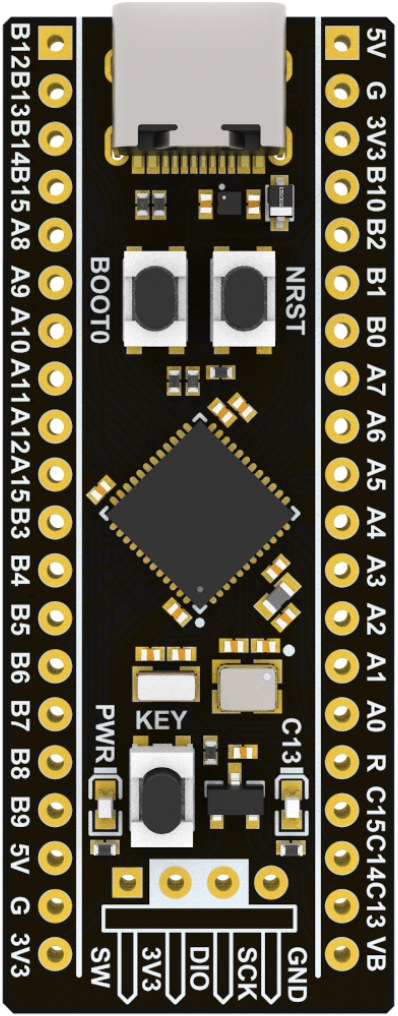
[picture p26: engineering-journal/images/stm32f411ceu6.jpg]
STM32 pinout


**Figure A3. STM32F411CEU6 pinout reference.**

---

## 14. Remaining Information Needed Before Final Submission

The current draft is strong enough to start the GitHub documentation, but the following items are still required to reach the best possible WRO documentation score:

| Missing item | Why it matters |
|---|---|
| Track width and wheel diameter | Needed for mechanical reproducibility and steering/turning reasoning. |
| Exact BMS and UPS model names | Needed for power reproducibility. |
| Measured current draw | Needed to turn estimated power budget into validated engineering evidence. |
| Jetson OS and Python version | Needed for reproducibility. |
| Full `requirements.txt` | Needed for software rebuild. |
| YOLO version, dataset size, annotation tool, training environment | Needed for vision system evaluation. |
| Inference FPS / ms per frame | Needed for performance evidence. |
| Test metrics: lap time, success rate, parking rate | Needed for testing and iteration scoring. |
| Final robot photos and team photo | Required by WRO Chapter 7. |
| Challenge video links | Required by WRO Chapter 7. |

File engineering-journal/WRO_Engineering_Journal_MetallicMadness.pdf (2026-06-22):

MetallicMadness - ARBIBOT Engineering Journal | Page 1


Draft 1 - replace TODO fields with final measured evidence before official WRO submission

# Engineering Journal MetallicMadness - ARBIBOT

## WRO 2026 Future Engineers - Self-Driving Cars

System wiring overview prepared for ARBIBOT documentation.

Field | Value
Team | MetallicMadness
Robot | ARBIBOT
Organization | Universidad Metropolitana, Caracas
Document status | Draft 1 - contains TODO markers for missing final evidence

MetallicMadness - ARBIBOT Engineering Journal | Page 2

# Table of Contents

1. Introduction
2. Team Overview
3. Design Goals and WRO Constraints
4. Overall System Architecture
5. Mobility and Mechanical Design
6. Power and Sensor Architecture
7. Software Architecture and Obstacle Strategy
8. Vision System and YOLO Training
9. Systems Thinking and Engineering Decisions
10. Testing, Failures, and Improvements
11. Reproducibility and Build Instructions
12. Media and Evidence Checklist
13. Appendices and Remaining Information Needed

This draft is organized around the WRO Appendix C scoring logic: mechanical design, power/sensor architecture, software and obstacle strategy, systems thinking, and reproducibility.

MetallicMadness - ARBIBOT Engineering Journal | Page 3

# 1. Introduction

ARBIBOT is a four-wheel autonomous vehicle designed for the WRO Future Engineers Self-Driving Cars challenge. The robot uses a split-control architecture: an NVIDIA Jetson Orin Nano performs high-level perception and navigation decisions, while an STM32F411 microcontroller handles low-level peripheral control, distance sensors, motor control, encoder feedback, and serial command execution.
The design objective is to build a stable self-driving robot able to complete the Open Challenge and Obstacle Challenge using sensor fusion between computer vision, ToF distance sensors, motor feedback, and deterministic control logic. The engineering focus is reliability under competition constraints: vehicle size, autonomous operation, random field configuration, lighting variation, sensor noise, power stability, and recovery from edge cases.

# 2. Team Overview

Role | Name | Summary
Student | Daniel Jose Denis Castillo | Electrical Engineering student at Universidad Metropolitana in Caracas. Strong interest in electronics, robotics, Python, AI models, and technical problem solving.
Student | Douglas Gabriel Ordaz Yanez | Electrical Engineering and Computer Engineering student at Universidad Metropolitana in Caracas. Strong interest in software development, coding logic, and game programming.
Tutor / Coach | Daniel Jose Denis Rodriguez | Electrical Engineer from Universidad Metropolitana with more than 25 years of experience in software engineering, telecommunications, AI, cybersecurity, embedded systems, and technology leadership.

# 3. Design Goals and WRO Constraints

Constraint / Requirement | ARBIBOT design response
Four-wheel vehicle, not differential drive | Rear-wheel drive with a front steering actuator. The rear wheels are mechanically linked through the drive system.
One steering actuator | MG996R servo drives a pushrod/tie-rod steering linkage.
Autonomous operation | Jetson and STM32 run onboard; no wireless control is used during a round.
Maximum dimensions | Current dimensions: 25 cm length x 15.6 cm width x 18 cm height.
Maximum weight | Current measured weight: 1.35 kg.
Challenge time | Estimated runtime is 20-30 minutes, above the 3-minute round requirement.
Randomized field | Software uses sensor fusion and state logic instead of hard-coded field layouts.

# 4. Overall System Architecture

ARBIBOT uses a two-controller architecture. The Jetson Orin Nano performs AI inference, camera processing, and navigation decisions. The STM32F411 executes deterministic low-level control for sensors, motor driver, encoder feedback, and serial communication.

Camera + YOLO + navigation logic
v
NVIDIA Jetson Orin Nano
| USB serial / DD-UART protocol v
STM32F411 Black Pill
|--- ToF sensors / IMU
|--- Cytron MD10C motor driver |--- Encoder feedback
|--- Sensor address/reset control

Separate power domains:

MetallicMadness - ARBIBOT Engineering Journal | Page 4
- Motor power: 3S Li-ion pack + BMS 3S 20A -> Cytron MD10C -> DC motor
- Jetson/logic power: Waveshare UPS -> Jetson + camera + Pololu servo controller

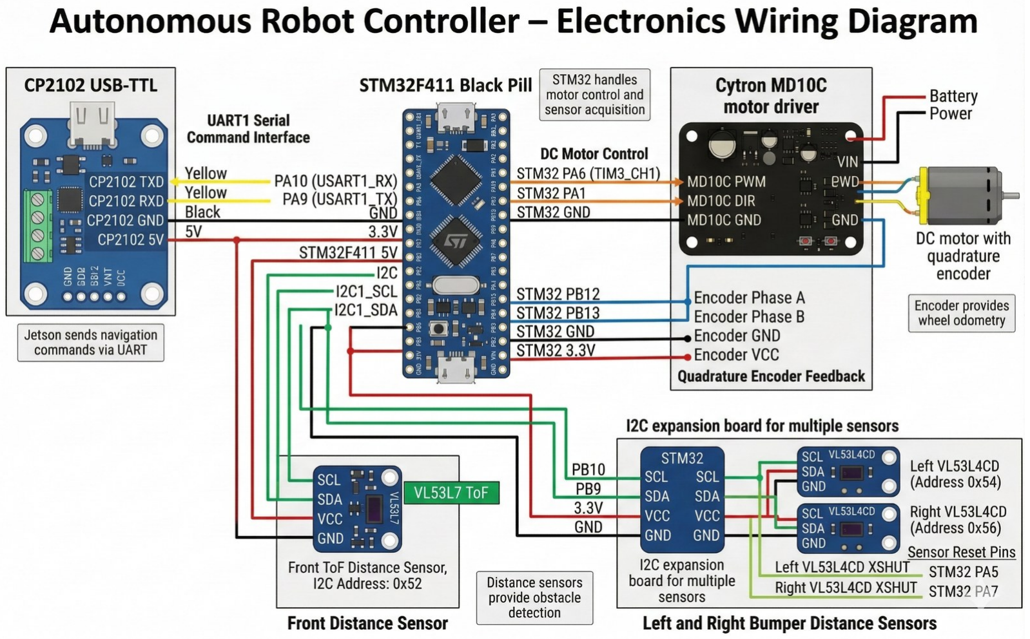
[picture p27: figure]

Figure 1. STM32F411 wiring and peripheral integration diagram.

# 5. Mobility and Mechanical Design

## 5.1 Mechanical summary

Item | Current design
Chassis | 3D printed chassis
Vehicle length / width / height | 25 cm x 15.6 cm x 18 cm
Weight | 1.35 kg
Wheelbase | 13.9 cm
Track width | TODO: measure distance between left and right wheels
Drive configuration | Rear-wheel drive
Steering | Servo-actuated pushrod steering with tie-rod linkage
Steering servo | MG996R, 5 V, approx. 9.4 kg-cm at 4.8 V
Drive motor | JGY-370B 12 V DC worm gear motor with encoder, 150 RPM

## 5.2 Steering mechanism

The vehicle uses a servo-actuated front steering mechanism. The steering servo moves a control arm connected to a pushrod. The pushrod actuates one front steering knuckle, and both front wheels are mechanically connected by a tie rod. Therefore, movement of one wheel is transferred to the other front wheel, producing synchronized front steering using a single steering actuator.
The mechanism is best described as a custom servo-driven pushrod and tie-rod steering linkage. It is Ackermann-inspired, but it should not be claimed as validated Ackermann geometry until inner and outer wheel steering angles are measured.

MetallicMadness - ARBIBOT Engineering Journal | Page 5


Figure 2. Steering linkage close-up showing pushrod and tie-rod connection.

## 5.3 Drive motor and encoder

ARBIBOT uses a JGY-370B 12 V mini worm gear DC motor with encoder feedback. The motor is a double-shaft DC gear motor with hall-coded tachymetry feedback and 150 RPM nominal no-load speed. The selected motor includes metal gears and self-locking behavior, which improves vehicle holding behavior when power is removed.

Encoder parameter | Value
Hall elements | 2 Hall sensors
Output type | AB-phase square wave
Basic pulse count | 11 PPR at motor shaft
Encoder voltage | 3.3 V / 5 V
Response frequency | 100 kHz
Firmware use | Distance by degrees and RPM estimation

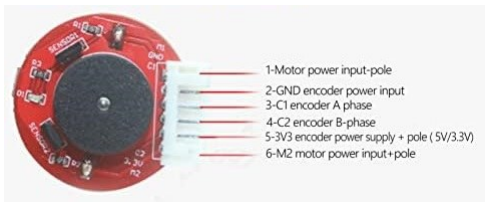
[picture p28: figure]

Figure 3. Encoder wiring reference for the JGY-370 motor.

## 5.4 Mechanical iterations and lessons learned

Issue tested | Problem observed | Improvement
Motor without encoder | No direct feedback for speed or distance. | Replaced with encoded JGY-370 motor.

MetallicMadness - ARBIBOT Engineering Journal | Page 6
Issue tested | Problem observed | Improvement
Single-shaft motor with gearbox | Torque transfer problems between gearbox gear and wheel gear. | Moved to more reliable double-shaft gear motor approach.
Thin wheels | Wheels slid on the track. | Preferred wider/higher-grip wheels.
Ultrasonic sensors | Lower precision and stability. | Replaced by ST VL53 laser ToF sensors.
Early bumper | Rubbing against tire; sensors too low. | Revised bumper geometry and sensor height.
Steering linkage | Limited steering range and alignment. | Adjusted servo arm, rods, and alignment screw.

# 6. Power and Sensor Architecture

## 6.1 Power architecture

ARBIBOT uses separated power paths for the motor system and the Jetson/logic system. This reduces the risk that motor and steering current peaks will create voltage dips, sensor noise, or serial communication failures.

Power domain | Components powered | Source / path
Motor power | Cytron MD10C and DC drive motor | 3 x 18650 Li-ion cells through BMS 3S 20A
STM32 power | STM32F411 low-level controller | USB/TTL 5 V supply
Jetson / vision power | Jetson Orin Nano and CSI camera | Waveshare UPS module, Jetson powered at 12 V
Steering power | Pololu servo controller and MG996R servo | Powered from Waveshare UPS system


Figure 4. BMS 3S 20 A module used for motor battery protection.

MetallicMadness - ARBIBOT Engineering Journal | Page 7

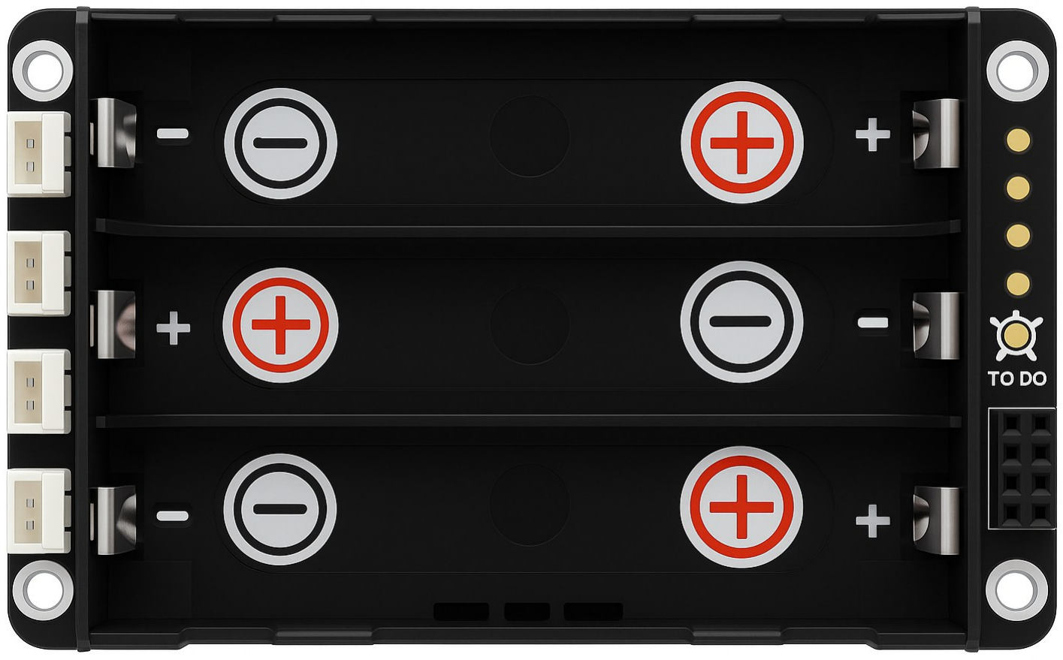
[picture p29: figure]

Figure 5. Waveshare UPS module used for the Jetson power domain.

## 6.2 Estimated power budget

The following power budget is an engineering estimate based on current component information. Final submission should replace estimates with measurements from an inline wattmeter, USB power meter, or bench supply.

Component | Voltage | Typical current | Peak current | Typical power | Peak power | Notes
Jetson Orin Nano | 12 V | ~2.1 A | ~3.3 A | 25 W | 40 W | Depends on AI workload and power mode.
STM32F411 | 3.3/5 V | ~10 mA | TODO | <0.1 W | TODO | Peripherals and clocks affect total.
MG996R servo | 5 V | 0.5-0.9 A | 1.5-2.5 A | 2.5-4.5 W | 7.5-12.5 W | Short steering peaks.
JGY-370B motor | 12 V | 0.2-0.3 A | 1.3-2.0 A | 2.4-3.6 W | 15.6-24 W | Peak during acceleration/stall.
VL53L4CD x3 | 3.3 V | 45-75 mA | TODO | 0.15-0.25 W | TODO | 15-25 mA each.
VL53L8CH | 3.3 V | TODO | TODO | TODO | TODO | Measure matrix ranging draw.
Camera IMX477 | CSI | TODO | TODO | TODO | TODO | Powered from Jetson.

Engineering interpretation: average consumption is dominated by the Jetson, while the motor and steering servo dominate short current peaks. The split power architecture reduces the chance that motor current spikes will reset the Jetson or corrupt sensor readings. Estimated runtime is 20-30 minutes, above the 3-minute challenge duration, but final validation should include voltage sag testing during acceleration and repeated steering.

## 6.3 Sensor architecture

Sensor | Qty | Placement | Main use
VL53L4CD | 3 | Front-right bumper, rear-right/middle between wheels, left/front bumper | Wall following, side correction, obstacle distance, parking support
VL53L8CH | 1 | Center front bumper | Front distance matrix and obstacle/wall perception
IMU | 1 | Low-level controller system | Gyroscope and accelerometer telemetry
IMX477 camera | 1 | Front/top camera mount | YOLO object detection and line/corner detection

The right-side VL53L4CD pair estimates heading relative to the wall. The difference between right-front and right-rear readings indicates whether the robot is angled toward or away from the wall, enabling a heading correction term in the lane controller.

## 6.4 I2C addressing and reset control

Sensor | Firmware address notation | XSHUT / reset pin
Left VL53L4CD | 0x52H | PA5

MetallicMadness - ARBIBOT Engineering Journal | Page 8
Sensor | Firmware address notation | XSHUT / reset pin
Right-front VL53L4CD | 0x54H | PA7
Right-rear VL53L4CD | 0x56H | PB14
Front VL53L8CH | 0x52H | TODO: confirm bus and reset handling

Note: final documentation should clarify whether addresses are written as 7-bit or 8-bit I2C addresses, and whether the VL53L8CH is isolated on a separate I2C bus. This avoids confusion because several ST ToF sensors share default address conventions.

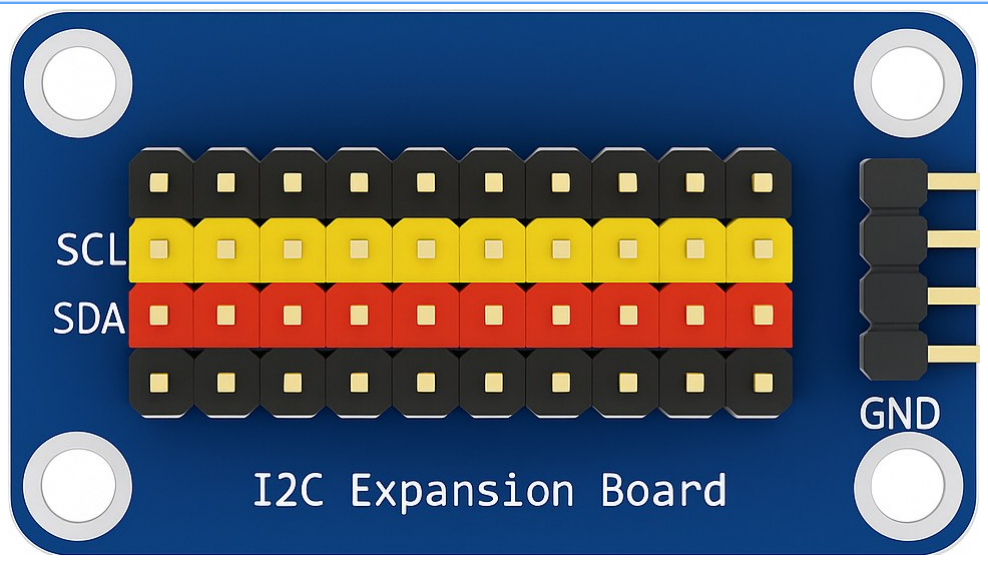
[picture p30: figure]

Figure 6. I2C expansion board used to simplify shared SDA/SCL and power distribution.


Figure 7. VL53L4CD ToF sensor module used for side/wall distance readings.

MetallicMadness - ARBIBOT Engineering Journal | Page 9

Figure 8. VL53L8CH front matrix ToF sensor module used for front distance perception.

## 6.5 Sensor calibration

Distance calibration is performed at fixed references from 120 cm down to 10 cm: 120, 110, 100, 90, 80, 70, 60, 50, 40, 30, 20, and 10 cm. A Python tool reads all sensors at each position while the car is moved through known distances. This process helps detect offsets, dead zones, and unstable ranges.

# 7. Software Architecture and Obstacle Strategy

## 7.1 Jetson software responsibilities

- CSI camera capture through GStreamer (`nvarguscamerasrc`) into OpenCV at 1280 x 720.
- Ultralytics YOLO inference using custom trained weights.
- Line/corner model for Open Challenge support.
- Pillar model for Obstacle Challenge detection: Green_Pillar, Red_Pillar.
- Lane/corner logic using camera detections, side ToF heading, and front ToF matrix data.
- Navigation decisions through PID/PDI control and threshold state logic.
- DD-UART command generation to the STM32.


Figure 9. NVIDIA Jetson Orin Nano selected for AI inference and high-level navigation.

MetallicMadness - ARBIBOT Engineering Journal | Page 10

## 7.2 STM32 software responsibilities

- Polls VL53L4CD side sensors.
- Polls front VL53L7CX/L8 8x8 to 4x4 matrix data.
- Reads IMU gyro/accelerometer data.
- Controls the Cytron MD10C using PWM and direction pins.
- Reads quadrature encoder signals using EXTI interrupts.
- Executes continuous motor commands, stop commands, set-speed commands, and move-by-degrees commands.
- Parses DD-UART frames, validates checksum, dispatches commands, and returns response frames.


Figure 10. STM32F411 Black Pill used as low-level peripheral controller.


Figure 11. Cytron MD10C motor driver used to control the 12 V DC drive motor.

## 7.3 Main Jetson modules

File | Role
main_challenge_01_v4.py | Open Challenge: camera-corner + heading wall-follow + front-matrix corner trigger.
main_challenge_02.py | Obstacle Challenge: pillar YOLO + PDI pass-side steering.
turn_models.py | CornerDetector line YOLO and result drawing.
Pillar_recognition.py | YOLO result to detection object: color, zone, area, nearest-pillar choice.
pillar_counter.py | Debounced enter/exit counting per pillar color.
pid_line_follower.py | PID lane controller: difference and single-wall modes.
sensor_distance_v3.py | Side-ToF + front-matrix reader/parser; extracts front barrier distance.
motor_driver.py | DD-UART motor command client.
servo_controller.py | Steering servo control over separate serial interface.
color_tuning.py | Per-camera color correction for detection models.

MetallicMadness - ARBIBOT Engineering Journal | Page 11

## 7.4 Main STM32 modules

File | Role
serial_dd_protocol.c/.h | DD-UART parsing, checksum validation, command dispatch, response.
motor_drv.c/.h | PWM, direction, set-speed, move-by-degrees, encoder count, RPM.
sensor_vl53l4cd.c | Side ToF distance sensors.
sensor_vl53l7ch.c | Front VL53L7CX/L8 4x4 matrix ToF.
sensor_imu.c | IMU gyro/accelerometer.
platform.c / platform2.c | I2C platform layer for ToF sensors.
main.c | Command dispatch and main loop.

## 7.5 State machine

WAITING_FOR_START
v
FIRST_SECTOR
v
STRAIGHT_DRIVE <------------------+
| pillar detected | | corner completed
v | |
OBSTACLE_HANDLING | |
+----> return to STRAIGHT_DRIVE |
| corner detected | |
v | |
CORNERING -------------------------+ |
v
FINISH / STOP

## 7.6 Navigation and obstacle strategy

Pillar detection: the YOLO model returns a class and bounding box. The class identifies color, the horizontal position determines left/center/right zone, and the bounding-box area estimates proximity. The largest area is treated as the nearest relevant pillar.
Obstacle rule behavior: red pillars are passed on the right side of the lane, and green pillars are passed on the left side. The robot computes the horizontal gap between the required pass-side boundary and the pillar edge, then uses a PDI controller to keep the pillar in the correct third of the image.
Corner detection fuses line/corner detections from the camera, front ToF matrix distance to the wall, and a right-wall-collapse fallback. The front matrix trigger fires around 1 m when enough matrix cells confirm a front barrier.
Lane holding uses the two right-side ToF sensors as a heading wall follower. The controller uses both distance error and the difference between right-front and right-rear readings, which helps prevent wall-to-wall oscillation.

## 7.7 DD-UART protocol

$ LEN(2 bytes, big-endian) CMD(2 bytes, big-endian) DATA(0..n) CHK(1 byte)

CHK = XOR checksum over LEN + CMD + DATA

CMD | Name | Payload | Response
0x0001 | READ_GYRO | None | IMU gyro
0x0002 | READ_ACCEL | None | IMU accel
0x0003 | READ_FRONT | None | Front matrix text
0x0004 | FORWARD continuous | None | Forward

MetallicMadness - ARBIBOT Engineering Journal | Page 12
CMD | Name | Payload | Response
0x0005 | REVERSE continuous | None | Reverse
0x0101 | FORWARD by degrees | uint16 LE degrees | ack
0x0102 | REVERSE by degrees | uint16 LE degrees | ack
0x0103 | STOP | None | Stopped
0x0104 | SET SPEED | uint8 percent | Speed updated
0x0105 | READ SIDES | None | RF, RR, LEFT distances

# 8. Vision System and YOLO Training

The vision system uses a Mini 12.3 MP HQ camera compatible with the NVIDIA Jetson platform. The camera is based on the IMX477 sensor and uses an M12 mount lens. The camera feeds the Jetson through MIPI CSI-2.

Model | Purpose | Classes / outputs
Pillar model | Obstacle Challenge traffic sign detection | Green_Pillar, Red_Pillar
Line/corner model | Open Challenge corner/line support | TODO: exact class names for blue/orange line model

YOLO was selected instead of simple color thresholding because lighting conditions, glare, shadows, and partial occlusion can shift raw color values. A trained detector can localize and classify pillars more robustly than fixed HSV thresholds. The software still uses color correction and confidence thresholds to reduce false positives.

Vision parameter | Current value
YOLO version | TODO: confirm YOLOv8, YOLO11, or other
Weights | Models/best_model_1.pt and line/corner weights
Pillar confidence threshold | 0.30
Corner line confidence threshold | 0.48
Dataset size | TODO: number of labeled images per model
Annotation tool | TODO: Roboflow, CVAT, labelImg, etc.
Training environment | TODO: PC GPU, Google Colab, Jetson, etc.
Jetson inference speed | TODO: FPS or ms/frame measured on robot

# 9. Systems Thinking and Engineering Decisions

## 9.1 Major design decisions

Decision | Alternatives considered | Reason for final choice
Jetson + STM32 split architecture | Single controller only | Jetson is strong for AI inference; STM32 is better for deterministic I/O and motor/sensor timing.
ToF sensors instead of ultrasonic | Ultrasonic modules | ToF sensors provided better precision and more stable short-range readings.
Encoded DC motor | Motor without encoder | Encoder enables RPM estimation and move-by-degrees control.
Two right-side sensors | Single distance sensor | Two readings reveal angle relative to wall; one reading only gives distance.
Separate power domains | Shared battery | Reduces brownouts, resets, and sensor/serial noise from motor peaks.
YOLO instead of color threshold | HSV thresholding | More robust to lighting, glare, and partial occlusion.
Pulsed critical serial commands | Single command transmission | Repeated start/stop commands improve reliability on shared serial bus.

## 9.2 Risk register

Risk / failure mode | Cause | Mitigation
Jetson brownout | AI load plus peripheral current peaks | Separate UPS power path for Jetson.

MetallicMadness - ARBIBOT Engineering Journal | Page 13
Risk / failure mode | Cause | Mitigation
Motor noise affects sensors | High current switching and common ground noise | Separated power paths and common ground discipline.
Serial frame lost | Shared sensor/motor serial bus busy | Sensor thread owns reads; motor commands fire-and-forget; critical commands are pulsed.
Lane wandering | Distance-only wall control ignores heading | Added right-front minus right-rear heading term.
False corner trigger | Single ToF matrix cell sees edge/wall artifact | Require at least two in-band cells before firing.
Late corner trigger | Floor cells distort matrix distance | Exclude floor-band cells and use row-specific barrier logic.
Pillar over-steering | High PDI gain and late reaction | Soften gains, lower steering clamp, and react earlier.
Tire slip | Thin wheels with low grip | Use wider / higher-grip wheels.

# 10. Testing, Failures, and Improvements

## 10.1 Software version evolution

Version | Description
v1 - main_challenge_01.py | Camera corner detection + open-loop center steering.
v2 - main_challenge_01_v2.py | Added PID wall-following and sensor/front-ToF corner fallbacks.
v3 - main_challenge_01_v3.py | Two-right-sensor follow + new VL53L8 4x4 matrix; abandoned because it became unstable and over-complex.
v4 - current Open Challenge | v2 proven base + new firmware sensors + 4x4 front-matrix trigger + RF-RR heading wall follower.
main_challenge_02.py | Current Obstacle Challenge: pillar YOLO + PDI pass-side steering on reliable v4 scaffolding.

## 10.2 Problems and fixes

Problem | Root cause | Fix
Turned too late and hit front wall | Front sensor swap to VL53L8 4x4; floor cells distorted distance estimate. | Excluded floor-band cells and used row-specific barrier distance.
Turned too soon | Lone matrix cell saw outer-wall corner. | Require at least two in-band cells to trigger a turn.
Car would not start or ran in reverse | Set-speed caused idle reverse behavior and single frame could drop. | Send forward first, interleave speed, and pulse commands.
Stop button did not always stop robot | Stop frame dropped during matrix scan. | Pulse stop command.
Side sensors read -1 | Parser mismatch with new firmware; YOLO load starved serial thread. | Updated parser and avoided heavy matrix polling until needed.
Lane wandered wall-to-wall | Distance-only PID was blind to vehicle heading. | Added RF-RR heading term.
Pillar steering full-lock / lost target | PDI gains too high and action started too close. | Reduced gains, lowered steering clamp, and started reaction earlier.

## 10.3 Current performance notes

Metric | Current value
Best lap time | TODO
Average lap time | TODO
Open Challenge success rate | TODO
Obstacle Challenge success rate | TODO
Parking success rate | TODO
Observed progress | Open Challenge reached approximately 2.5 of 3 laps before lane-keeping failure; single clean laps achieved repeatedly.
Front matrix trigger | Fires reliably around 100 cm based on current tests.

MetallicMadness - ARBIBOT Engineering Journal | Page 14

# 11. Reproducibility and Build Instructions

This section must be completed before final submission so another team or judge can rebuild and run the robot with reasonable effort.

## 11.1 Hardware assembly overview

1. 3D print or manufacture chassis and mounts.
2. Install rear drive motor and mechanically connect rear wheels.
3. Install front steering knuckles, tie rod, steering servo, servo horn, and pushrod.
4. Mount Jetson Orin Nano and UPS module.
5. Mount STM32F411 and connect sensors, motor driver, and encoder.
6. Mount front bumper and install VL53 sensors at final tested height.
7. Mount IMX477 camera and adjust pitch/field of view.
8. Wire motor battery through BMS to Cytron MD10C.
9. Wire logic power and grounds, ensuring shared ground reference where required.
10. Run sensor and steering-center calibration before test laps.

## 11.2 STM32 flashing

TODO: add exact flashing instructions. Include STM32CubeIDE project path, build target, ST-Link or bootloader method, and firmware binary name.

## 11.3 Jetson setup

TODO: add exact OS, Python version, packages, virtual environment, and startup commands. Include requirements.txt in the repository.

## 11.4 Run procedure

1. Place robot in starting zone completely switched off.
2. Power on using the allowed power switch.
3. Wait for WAITING_FOR_START state.
4. After judge command, press the single start button.
5. Robot begins autonomous operation.
6. Robot stops autonomously at the end of the challenge or when a stop condition is met.

# 12. Media and Evidence Checklist

Item | Status
Vehicle front photo | TODO
Vehicle rear photo | TODO
Vehicle left side photo | TODO
Vehicle right side photo | TODO
Vehicle top photo | TODO
Vehicle bottom photo | TODO

MetallicMadness - ARBIBOT Engineering Journal | Page 15
Item | Status
Close-up of sensor mounts | TODO
Close-up of steering mechanism | Available: steering close-up photo
Close-up of motor + encoder installation | TODO
Team photo | TODO
Open Challenge video, minimum 30 seconds | TODO: YouTube link
Obstacle Challenge video, minimum 30 seconds | TODO: YouTube link

# 13. Appendix A - Component Image References


Figure A1. CP2102 USB-TTL module used for serial communication/debugging.


Figure A2. Pololu servo controller used for steering servo control.

MetallicMadness - ARBIBOT Engineering Journal | Page 16

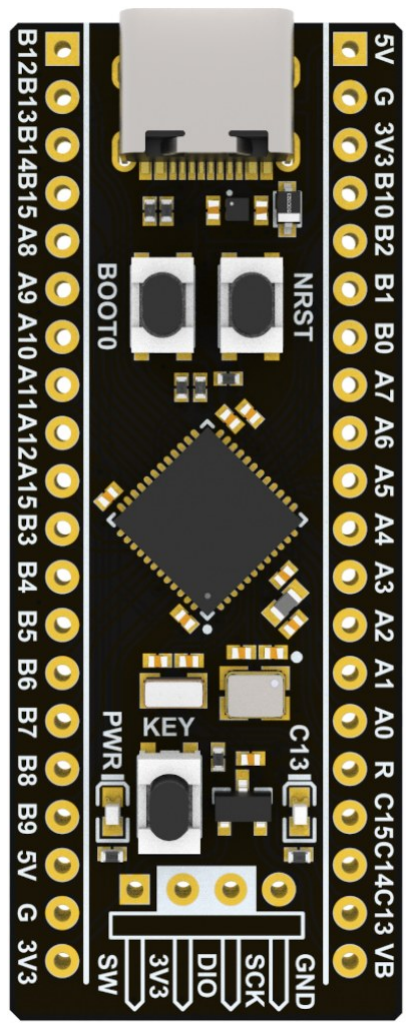
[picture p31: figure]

Figure A3. STM32F411CEU6 pinout reference.

# 14. Remaining Information Needed Before Final Submission

Missing item | Why it matters
Track width and wheel diameter | Needed for mechanical reproducibility and steering/turning reasoning.
Exact BMS and UPS model names | Needed for power reproducibility.
Measured current draw | Turns estimated power budget into validated engineering evidence.
Jetson OS and Python version | Needed for reproducibility.
Full requirements.txt | Needed for software rebuild.
YOLO version, dataset size, annotation tool, training environment | Needed for vision system evaluation.
Inference FPS / ms per frame | Needed for performance evidence.
Test metrics: lap time, success rate, parking rate | Needed for testing and iteration scoring.
Final robot photos and team photo | Required by WRO Chapter 7.
Challenge video links | Required by WRO Chapter 7.

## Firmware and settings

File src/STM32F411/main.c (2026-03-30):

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
/* Includes ------------------------------------------------------------------*/
#include "main.h"
#include <motor_drv.h>
#include <stdlib.h>
#include <string.h>
#include <stdio.h>
#include "sensor_vl53l7ch.h"
#include "sensor_imu.h"
#include "serial_dd_protocol.h"
#include "sensor_vl53l4cd.h"

/* GPIO defines for VL53L4CD XSHUT pins */
#define VL53L4CD_LEFT_XSHUT_GPIO_Port GPIOA
#define VL53L4CD_LEFT_XSHUT_Pin       GPIO_PIN_5
#define VL53L4CD_RIGHT_XSHUT_GPIO_Port GPIOA
#define VL53L4CD_RIGHT_XSHUT_Pin       GPIO_PIN_7

/* Global variables */
VL53L4CD_ResultsData_t left_results;
VL53L4CD_ResultsData_t right_results;
Dev_t left_sensor_address = 0x54;  // New I2C address
Dev_t right_sensor_address = 0x56; // New I2C address

/* Global motor speed (0–100%) */
uint8_t global_motor_speed = 50;  // default speed

I2C_HandleTypeDef hi2c1;
I2C_HandleTypeDef hi2c2;

TIM_HandleTypeDef htim3;
TIM_HandleTypeDef htim9;

UART_HandleTypeDef huart1;

void SystemClock_Config(void);
static void MX_GPIO_Init(void);
static void MX_I2C1_Init(void);
static void MX_USART1_UART_Init(void);
static void MX_I2C2_Init(void);
static void MX_TIM3_Init(void);
static void MX_TIM9_Init(void);

/* USER CODE BEGIN 0 */
extern volatile uint8_t new_message_ready;
extern volatile DD_Uart_Message received_message;
extern TIM_HandleTypeDef htim3;  // or htim9, htim10 depending on your config

TIM_HandleTypeDef* motor_pwm_tim = &htim3;
uint32_t motor_pwm_channel = TIM_CHANNEL_1;  // or whatever channel you use

int _write(int file, char *ptr, int len) {
    HAL_UART_Transmit(&huart1, (uint8_t *)ptr, len, HAL_MAX_DELAY);
    return len;
}

/* Helper to enable one sensor at a time */
void VL53L4CD_Enable(GPIO_TypeDef* port, uint16_t pin) {
    HAL_GPIO_WritePin(port, pin, GPIO_PIN_SET);
    HAL_Delay(10);
}

void VL53L4CD_Disable(GPIO_TypeDef* port, uint16_t pin) {
    HAL_GPIO_WritePin(port, pin, GPIO_PIN_RESET);
    HAL_Delay(10);
}

/* Initialization routine for both sensors */
void init_dual_vl53l4cd_sensors() {
    VL53L4CD_Disable(VL53L4CD_LEFT_XSHUT_GPIO_Port, VL53L4CD_LEFT_XSHUT_Pin);
    VL53L4CD_Disable(VL53L4CD_RIGHT_XSHUT_GPIO_Port, VL53L4CD_RIGHT_XSHUT_Pin);

    // Init LEFT
    VL53L4CD_Enable(VL53L4CD_LEFT_XSHUT_GPIO_Port, VL53L4CD_LEFT_XSHUT_Pin);
    VL53L4CD_SensorInit(0x52);  // Default address
    VL53L4CD_SetI2CAddress(0x52, left_sensor_address);
    VL53L4CD_StartRanging(left_sensor_address);

    // Init RIGHT
    VL53L4CD_Enable(VL53L4CD_RIGHT_XSHUT_GPIO_Port, VL53L4CD_RIGHT_XSHUT_Pin);
    VL53L4CD_SensorInit(0x52);
    VL53L4CD_SetI2CAddress(0x52, right_sensor_address);
    VL53L4CD_StartRanging(right_sensor_address);
}

/* USER CODE END 0 */

/**
  * @brief  The application entry point.
  * @retval int
  */
int main(void)
{

  /* MCU Configuration--------------------------------------------------------*/

  /* Reset of all peripherals, Initializes the Flash interface and the Systick. */
  HAL_Init();

  /* Configure the system clock */
  SystemClock_Config();

  /* Initialize all configured peripherals */
  MX_GPIO_Init();
  MX_I2C1_Init();
  MX_USART1_UART_Init();
  MX_I2C2_Init();
  MX_TIM3_Init();
  MX_TIM9_Init();
  /* USER CODE BEGIN 2 */

  motor_init(&htim3, TIM_CHANNEL_1, MOTOR_DIR_GPIO_Port, MOTOR_DIR_Pin);

	printf("Hello, UART via CP2102!\n");

	// IMU sensor variables
	int16_t ax, ay, az, gx, gy, gz;

//	// Initialize IMU
//	if (sensor_imu_init(&hi2c2) != HAL_OK) {
//	  printf("Failed to initialize IMU\n");
//	  while (1);
//	}
	/*********************************/
	/*   VL53L7CX ranging variables  */
	/*********************************/

	VL53L7CX_Configuration dev;
	VL53L7CX_ResultsData results;
	uint8_t status, isReady, loop = 0;


	/*********************************/
	/*   Power on sensor and init    */
	/*********************************/
	uint8_t vl53l7ch_available = 0;
	status = sensor_vl53l7ch_init(&dev);
	if (status) {
	    printf("VL53L7CX ULD Loading failed\r\n");
	    vl53l7ch_available = 0;
	} else {
	    vl53l7ch_available = 1;
		/*********************************/
		/*         Ranging loop          */
		/*********************************/
	    status = sensor_vl53l7ch_start_ranging(&dev);
	    if (status) {
	        printf("VL53L7CX start ranging failed\r\n");
	        vl53l7ch_available = 0;
	    }
	}



//	// -------------------------------------------------------
//	// Now, immediately after init/start, read one 8×8 frame
//	// (or wrap in a while(1) to continuously print for debugging).
//	// -------------------------------------------------------
//	while (1) {
//	    // 1) Wait until data is ready
//	    status = sensor_vl53l7ch_check_data_ready(&dev, &isReady);
//	    if (status != 0) {
//	        printf("Error checking data ready: %u\n", status);
//	        break;
//	    }
//	    if (!isReady) {
//	        HAL_Delay(10);
//	        continue;
//	    }
//
//	    // 2) Get the 8×8 ranging data
//	    status = sensor_vl53l7ch_get_ranging_data(&dev, &results);
//	    if (status != 0) {
//	        printf("Error getting VL53L7CX data: %u\n", status);
//	        break;
//	    }
//
//	    // 1) Print the raw 8×8 distance matrix
//	   printf("Distances (mm):\r\n");
//	   for (uint8_t row = 0; row < 8; row++) {
//		   for (uint8_t col = 0; col < 8; col++) {
//			   uint8_t idx = row * 8 + col;
//			   // Print each distance as a 4‐digit field
//			   printf("%4u", results.distance_mm[idx]);
//			   if (col < 7) {
//				   printf(" ");
//			   }
//		   }
//		   printf("\r\n");
//	   }
//	   printf("\r\n");  // blank line separator
//
//	   // 2) Print the raw 8×8 status matrix
//	   printf("Statuses:\r\n");
//	   for (uint8_t row = 0; row < 8; row++) {
//		   for (uint8_t col = 0; col < 8; col++) {
//			   uint8_t idx = row * 8 + col;
//			   // Print each status as a 2‐digit decimal (pad if desired)
//			   printf("%2u", results.target_status[idx]);
//			   if (col < 7) {
//				   printf(" ");
//			   }
//		   }
//		   printf("\r\n");
//	   }
//	   printf("\r\n");  // blank line separator
//
//	    // 5) Delay before next frame
//	    HAL_Delay(100);
//	}


	/*********************************/
	/*   VL53L4CD   variables        */
	/*********************************/
	VL53L4CD_ResultsData_t left_results;
	VL53L4CD_ResultsData_t right_results;
	Dev_t left_sensor_address = 0x54;  // New I2C address
	Dev_t right_sensor_address = 0x56; // New I2C address


	/*********************************/
	/*   Power on sensor and init    */
	/*********************************/
	init_dual_vl53l4cd_sensors();

	/*********************************/
	/*         Read Data vl53l4cd    */
	/*********************************/
	// --- VL53L4CD Test Read After Init ---
	uint8_t isReadyL = 0, isReadyR = 0;
	char test_buf[100];

	HAL_Delay(50);  // Allow sensor to stabilize

	VL53L4CD_CheckForDataReady(left_sensor_address, &isReadyL);
	if (isReadyL) {
	    VL53L4CD_ClearInterrupt(left_sensor_address);
	    VL53L4CD_GetResult(left_sensor_address, &left_results);
	    snprintf(test_buf, sizeof(test_buf), "INIT TEST - LEFT: %d mm\r\n", left_results.distance_mm);
//	    HAL_UART_Transmit(&huart1, (uint8_t *)test_buf, strlen(test_buf), 100);
	}

	VL53L4CD_CheckForDataReady(right_sensor_address, &isReadyR);
	if (isReadyR) {
	    VL53L4CD_ClearInterrupt(right_sensor_address);
	    VL53L4CD_GetResult(right_sensor_address, &right_results);
	    snprintf(test_buf, sizeof(test_buf), "INIT TEST - RIGHT: %d mm\r\n", right_results.distance_mm);
//	    HAL_UART_Transmit(&huart1, (uint8_t *)test_buf, strlen(test_buf), 100);
	}


	uint32_t led_blink_counter = 0;  // Counter for LED blinking

  /* USER CODE END 2 */

  /* Infinite loop */
  /* USER CODE BEGIN WHILE */
  while (1)
  {

	motor_update();

	// LED blinking every 500ms (e.g., increment counter every 100ms)
	if (led_blink_counter++ >= 500) {
		HAL_GPIO_TogglePin(LED_GPIO_Port, LED_Pin);  // Toggle LED
		led_blink_counter = 0;  // Reset the counter
	}

	// Check if a new message is received
	if (new_message_ready) {
		// Process the received_message
		new_message_ready = 0;  // Reset flag

		switch (received_message.command) {
			case 0x0001:  // READ_GYRO
//				if (sensor_imu_read_gyro(&hi2c2, &gx, &gy, &gz) == HAL_OK) {
//					// Prepare data as a string
//					char gyro_data[50];
//					snprintf(gyro_data, sizeof(gyro_data), "Gyro: X=%d, Y=%d, Z=%d", gx, gy, gz);
//
//					// Send response to PC
//					send_response(0x0001, gyro_data);
//				}
				break;
			case 0x0002:  // READ_ACCEL
//				if (sensor_imu_read_accel(&hi2c2, &ax, &ay, &az) == HAL_OK) {
//					// Prepare data as a string
//					char accel_data[50];
//					snprintf(accel_data, sizeof(accel_data), "Accel: X=%d, Y=%d, Z=%d", ax, ay, az);
//
//					// Send response to PC
//					send_response(0x0002, accel_data);
//				}
				break;
			case 0x0003:  // READ_DISTANCE_SENSOR
			{
				if (!vl53l7ch_available) {
					send_response(0x0003, "VL53L7CX not available");
					break;
				}

				status = sensor_vl53l7ch_check_data_ready(&dev, &isReady);
				if (status) {
					send_response(0x0003, "VL53L7CX check error");
					break;
				}

				if (!isReady) {
					send_response(0x0003, "Data not ready");
					break;
				}

			    status = sensor_vl53l7ch_check_data_ready(&dev, &isReady);
			    if (!isReady) {
			        send_response(0x0003, "Data not ready");
			        break;
			    }

			    status = sensor_vl53l7ch_get_ranging_data(&dev, &results);
			    if (status) {
			        send_response(0x0003, "Error getting data");
			        break;
			    }

			    // Build a single buffer containing both the 8×8 distances and the 8×8 statuses
			    char distance_data[2048];
			    memset(distance_data, 0, sizeof(distance_data));
			    char *ptr = distance_data;
			    int   offset = 0;

			    // 1) Header: stream count
			    offset += snprintf(ptr + offset,
			                       sizeof(distance_data) - offset,
			                       "Stream %u\r",
			                       dev.streamcount);

			    // 2) Print the 8×8 distance matrix
			    offset += snprintf(ptr + offset,
			                       sizeof(distance_data) - offset,
			                       "Distances (mm):\r");
			    for (uint8_t row = 0; row < 8; row++) {
			        for (uint8_t col = 0; col < 8; col++) {
			            uint8_t idx = row * 8 + col;
			            offset += snprintf(ptr + offset,
			                               sizeof(distance_data) - offset,
			                               "%4u",
			                               results.distance_mm[idx]);
			            if (col < 7) {
			                offset += snprintf(ptr + offset,
			                                   sizeof(distance_data) - offset,
			                                   " ");
			            }
			        }
			        offset += snprintf(ptr + offset,
			                           sizeof(distance_data) - offset,
			                           "\r");
			    }
			    offset += snprintf(ptr + offset,
			                       sizeof(distance_data) - offset,
			                       "\r");

			    // 3) Print the 8×8 status matrix
			    offset += snprintf(ptr + offset,
			                       sizeof(distance_data) - offset,
			                       "Statuses:\r");
			    for (uint8_t row = 0; row < 8; row++) {
			        for (uint8_t col = 0; col < 8; col++) {
			            uint8_t idx = row * 8 + col;
			            offset += snprintf(ptr + offset,
			                               sizeof(distance_data) - offset,
			                               "%3u",
			                               results.target_status[idx]);
			            if (col < 7) {
			                offset += snprintf(ptr + offset,
			                                   sizeof(distance_data) - offset,
			                                   " ");
			            }
			        }
			        offset += snprintf(ptr + offset,
			                           sizeof(distance_data) - offset,
			                           "\r");
			    }
			    offset += snprintf(ptr + offset,
			                       sizeof(distance_data) - offset,
			                       "\r");

			    // 4) Send the combined buffer back
			    send_response_len(0x0003, distance_data, offset);
			    HAL_Delay(5);
			    break;
			}


			case 0x0004:  // FORWARD
			{
			    motor_forward(global_motor_speed);
			    send_response(0x0004, "Forward");
			    break;
			}
			case 0x0005:  // REVERSE
			{
			    motor_reverse(global_motor_speed);
			    send_response(0x0005, "Reverse");
			    break;
			}
			case 0x0101:  // FORWARD with degrees
			{
				uint16_t payload_len = received_message.length - 7;
				if (payload_len < 2) {
				    send_response(0x0101, "ERR: degree payload too short");
				    break;
				}
				uint16_t deg = received_message.data[0] | (received_message.data[1] << 8);
			    motor_forward_degrees(deg,  global_motor_speed);
			    send_response(0x0101, "Moved Forward by degrees");
			    break;
			}
			case 0x0102:  // REVERSE with degrees
			{
				uint16_t payload_len = received_message.length - 7;
				if (payload_len < 2) {
				    send_response(0x0101, "ERR: degree payload too short");
				    break;
				}
				uint16_t deg = received_message.data[0] | (received_message.data[1] << 8);
			    motor_reverse_degrees(deg,  global_motor_speed);
			    send_response(0x0102, "Moved Reverse by degrees");
			    break;
			}
			case 0x0103:  // STOP
			{
			  motor_stop();
			  send_response(0x0103, "Stopped");
			  break;
			}
			case 0x0104:  // SPEED
			{
			    global_motor_speed = received_message.data[0];
			    motor_set_speed(global_motor_speed);
			    send_response(0x0104, "Speed updated");
			    break;
			}
			/* In the main command switch-case: */
			case 0x0105:  // READ VL53L4CD LEFT & RIGHT
			{
			    char buf[100];
			    uint8_t isReadyL = 0, isReadyR = 0;
			    int len = 0;

			    VL53L4CD_CheckForDataReady(left_sensor_address, &isReadyL);
			    if (isReadyL) {
			        VL53L4CD_ClearInterrupt(left_sensor_address);
			        VL53L4CD_GetResult(left_sensor_address, &left_results);
			    }

			    VL53L4CD_CheckForDataReady(right_sensor_address, &isReadyR);
			    if (isReadyR) {
			        VL53L4CD_ClearInterrupt(right_sensor_address);
			        VL53L4CD_GetResult(right_sensor_address, &right_results);
			    }

			    // Build combined message
			    len = snprintf(buf, sizeof(buf),
			                   "LEFT: %d mm | RIGHT: %d mm",
			                   isReadyL ? left_results.distance_mm : -1,
			                   isReadyR ? right_results.distance_mm : -1);

			    send_response_len(0x0105, buf, len);
			    break;
			}


			default:
				printf("Unknown command received\n");
				break;
		}


		// Reset the message length after processing
		received_message.length = 0;


	}

    // Read encoder data for RPM calculation
    uint32_t rpm = motor_get_rpm();
//    printf("Motor RPM: %lu\n", rpm);

	// Delay to make sure the LED toggle is visible
	HAL_Delay(1);  // Small delay (1ms) to allow for blinking without blocking other processes
  }
    /* USER CODE END WHILE */

    /* USER CODE BEGIN 3 */
  status = sensor_vl53l7ch_stop_ranging(&dev);
  printf("End of ULD demo\n");
  /* USER CODE END 3 */
}

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


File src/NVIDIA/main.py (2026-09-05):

#!/usr/bin/env python3
"""
main_challenge_v7.py  --  v6, plus backing out of a wedge.

THE ONLY DIFFERENCE FROM v6 is the unwedge hook in the main loop: when the car
has stopped moving against something, straighten, reverse an inch, restore the
steering it had, and carry on. Everything else -- perception, the state
machine, the turn profiles, the PID -- is v6 unchanged, so a v7 run stays
comparable with a v6 run.

The detection and the maneuver live in unwedge.py, imported not copied: the
robot cannot OBSERVE hitting a wall (no bumper, no IMU, no encoder feedback,
no current sensing), so the trigger is an inference, and the inference is the
part worth getting right once. See behavior_manager.REVERSE_* and STUCK_*.

NOTE ON KEEPING TWO MAINS. This file is a copy of v6's loop, so a fix made in
one will NOT reach the other. Deliberate for now -- v6 stays as the known-good
program while v7 is on trial -- but it is a debt, not a design: collapse them
behind B.REVERSE_UNWEDGE once v7 has proved out on the mat.

v6's own header follows.

three inputs, one controller.

    CORNER CLASSIFIER   names the turn and its profile
    WALL CLASSIFIER     names the kind of steering correction
    ToF SENSORS + PID   decide how much, and when the car has arrived

WHAT CHANGED FROM v5, AND WHY

v5 found corners with the LINE DETECTOR: it looked for the blue/orange corner
lines, derived a direction from the nearest line's colour, estimated "closeness"
from where that line sat in the image, and then drove every corner with the same
blind arc. Four things had to go right, and on the track they routinely did not:

  * the direction flipped left/right within a single approach (left,left,left,
    right,right -- and it committed on the last frame, into a wall);
  * `both=0` on almost every approach, so the direction rested on the weakest
    evidence available -- a lone line whose colour is unreliable;
  * closeness is a position IN THE IMAGE, not a distance, so it said "a corner is
    ahead" and never "you are there now" -- it once fired with the front ToF
    still reading 1082 mm;
  * one arc for every corner produced exits anywhere from R=33 to R=505.

The corner CLASSIFIER answers all of that in one output. It names the turn
(left/right) AND its severity (close/normal/open), so the direction needs no
vote, the severity picks the steering profile, and the ToF says when to go. Same
approach as the wall classifier, which is the one perception component that has
been consistently right on this robot.

WHAT IS UNCHANGED, DELIBERATELY
    the state machine        behavior_manager.py  (v5's, with the classifier
                             route added -- the priority order, the ToF vetoes,
                             the re-arm guard and the emergency escalation all
                             still apply)
    race bookkeeping         race_manager.py
    the ToF reader and       imported from main_challenge_01_v4 / v5, never
    wall follower            copied -- two copies always drift

STATUS: the logic in behavior_manager.py and race_manager.py is unit-tested off
robot. EVERYTHING IN THIS FILE touches hardware and has NOT been run. Bench it
with DRY_RUN = True (no motor) before letting it drive.
"""

import time

import cv2
import Jetson.GPIO as GPIO

import behavior_manager as B
from behavior_manager import BehaviorManager, Percept
from race_manager import RaceManager
from color_tuning_Dualcam import (CAM_WIDTH, apply_color_tuning,
                                  camera_pipeline, load_params)
from motor_driver import MotorSerial
from pid_line_follower import LineFollowerPID
from servo_controller import ServoController
from robot_io import (CornerTriggers, HeadingWallFollower, SensorAdapter,
                      button_pressed, set_pin, sleep_with_abort, valid_tof,
                      wait_for_button_press)
# The dual-camera pillar PID, IMPORTED not copied -- pillar_pid_dualcam.py is
# the one place the strip geometry and the steering sign live, and it carries
# the --selftest that proves them.
from unwedge import StuckDetector, reverse_nudge
from pillar_pid_dualcam import (PillarPID, Strip, choose as choose_pillar,
                                detect as detect_pillars, placed as pillar_placed)


# =========================================================
# HARDWARE / PORTS
# =========================================================

MOTOR_PORT = "/dev/ttyUSB0"
SENSOR_PORT = "/dev/ttyUSB0"     # same STM32 -> shared serial, sensor owns reads
SERVO_PORT = "/dev/ttyACM0"
SERVO_BAUD = 9600
# The button pin lives with set_pin()/button_pressed() in robot_io, which is
# the only place that reads it. Nothing here to edit.

DRY_RUN = False

# Shutdown only. The motor runs in forward_continuous, so a lost STOP frame
# means the car keeps going after the program exits -- see the finally block.
MOTOR_STOP_TRIES = 5
MOTOR_STOP_TIMEOUT_S = 0.4                  # True = never command the motor (bench testing)

# =========================================================
# MODELS -- only two now
# =========================================================

MODELS_DIR = "/home/daniel/WRO2026-MetallicMadness/Models"
CORNER_MODEL = f"{MODELS_DIR}/Best_Model_Corner_v3.pt"   # corner-TYPE classifier
WALL_MODEL = f"{MODELS_DIR}/Walls_model_v3.pt"
# Loaded ONLY when behavior_manager.PILLAR_PID_ENABLED. A detector on two full
# 1280x720 frames is far heavier than the two 224px classifiers, so challenge 1
# -- which has no pillars -- should not pay for it.
PILLAR_MODEL = f"{MODELS_DIR}/Pillar_model_v1.pt"

PANE = B.PANE
CAM_IDS = B.CAM_IDS
CLASS_BACKS_TRIGGER_FRAMES = B.CLASS_BACKS_TRIGGER_FRAMES
CORNER_EVERY = B.CORNER_EVERY
WALL_EVERY = B.WALL_EVERY
TURN_WALL_HZ = B.TURN_WALL_HZ

CRUISE_SPEED_PCT = B.CRUISE_SPEED_PCT
FINISH_DRIVE_S = B.FINISH_DRIVE_S

WALL_FOLLOW_MODE = B.WALL_FOLLOW_MODE
WALL_TARGET_MM = B.WALL_TARGET_MM
WF_KH, WF_KD = B.WF_KH, B.WF_KD
WF_RR_OFFSET_MM = B.WF_RR_OFFSET_MM
WF_OUT_LIMIT = B.WF_OUT_LIMIT
WF_DEADBAND = B.WF_DEADBAND
WF_HEADING_MAX_MM = B.WF_HEADING_MAX_MM

PID_KP, PID_KI, PID_KD = B.PID_KP, B.PID_KI, B.PID_KD
PID_OUT_LIMIT = B.PID_OUT_LIMIT
PID_DEADBAND = B.PID_DEADBAND
PID_MEDIAN_WINDOW = B.PID_MEDIAN_WINDOW
PID_SLEW_LIMIT = B.PID_SLEW_LIMIT
PID_KH = B.PID_KH

SIDE_MAX_AGE_S = B.SIDE_MAX_AGE_S
LR_HZ = B.LR_HZ
FRONT_HZ = B.FRONT_HZ
DEBUG_HZ = B.DEBUG_HZ


# =========================================================
# PERCEPTION -- two classifiers, one composite
# =========================================================
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

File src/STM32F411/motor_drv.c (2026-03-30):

#include "motor_drv.h"
#include "stm32f4xx_hal.h"

static TIM_HandleTypeDef *motor_pwm_tim;
static uint32_t motor_pwm_channel;
static GPIO_TypeDef *motor_dir_port;
static uint16_t motor_dir_pin;

static volatile int32_t encoder_count = 0;
static volatile uint32_t last_encoder_time = 0;
static volatile uint32_t last_encoder_count = 0;

#define PULSES_PER_REV 1595

typedef struct {
    int active;
    int direction;      // 1 = forward, -1 = reverse
    int32_t target_ticks;
    uint8_t speed;
} MotorMotion;

static volatile MotorMotion motion = {0};

void motor_init(TIM_HandleTypeDef *pwm_tim, uint32_t pwm_channel, GPIO_TypeDef *dir_port, uint16_t dir_pin)
{
    motor_pwm_tim = pwm_tim;
    motor_pwm_channel = pwm_channel;
    motor_dir_port = dir_port;
    motor_dir_pin = dir_pin;

    HAL_TIM_PWM_Start(motor_pwm_tim, motor_pwm_channel);
    motor_set_speed(0);
}

void motor_set_speed(uint8_t speed_percent)
{
    if (speed_percent > 100) speed_percent = 100;

    if (motor_pwm_tim == NULL) {
        printf("motor_pwm_tim is NULL!\n");
        Error_Handler();
    }

    printf("Timer Period: %lu\n", motor_pwm_tim->Init.Period);
    // Calculate the pulse value based on the speed percentage
    uint32_t pulse = (motor_pwm_tim->Init.Period + 1) * speed_percent / 100;

    // Ensure the pulse value is within the valid range
    if (pulse > motor_pwm_tim->Init.Period) {
        pulse = motor_pwm_tim->Init.Period;
    }

    // Set the compare value for the PWM signal
    __HAL_TIM_SET_COMPARE(motor_pwm_tim, motor_pwm_channel, pulse);
}

void motor_forward(uint8_t speed_percent)
{
    HAL_GPIO_WritePin(motor_dir_port, motor_dir_pin, GPIO_PIN_SET);
    motor_set_speed(speed_percent); // or any desired speed
}

void motor_reverse(uint8_t speed_percent)
{
    HAL_GPIO_WritePin(motor_dir_port, motor_dir_pin, GPIO_PIN_RESET);
    motor_set_speed(speed_percent); // or any desired speed
}



//void motor_forward_degrees(uint16_t degrees, uint8_t speed_percent)
//{
//	printf("[DEBUG] motor_forward_degrees called\n");
//	printf("[DEBUG] Degrees: %u\n", degrees);
//    encoder_count = 0;
//    int32_t target_ticks = ((degrees * PULSES_PER_REV) + 359) / 360;
//    printf("[DEBUG] Target Ticks: %ld\n", target_ticks);
//
//    motor_set_speed(speed_percent);
//    HAL_GPIO_WritePin(motor_dir_port, motor_dir_pin, GPIO_PIN_SET);
//
//    printf("before look\n");
//
//    while (encoder_count < target_ticks) {
//        printf("ENC: now=%ld, target=%ld\n", encoder_count, target_ticks);
//
//    }
//
//    motor_stop();
//    printf("[DEBUG] motor_stop() called. Final encoder count: %ld\r\n", encoder_count);
//}

void motor_forward_degrees(uint16_t degrees, uint8_t speed_percent)
{
    printf("[DEBUG] motor_forward_degrees called\n");

    encoder_count = 0;

    motion.target_ticks = ((degrees * PULSES_PER_REV) + 359) / 360;
    motion.direction = 1;
    motion.speed = speed_percent;
    motion.active = 1;

    HAL_GPIO_WritePin(motor_dir_port, motor_dir_pin, GPIO_PIN_SET);
    motor_set_speed(speed_percent);

    printf("[DEBUG] Target Ticks: %ld\n", motion.target_ticks);
}

//void motor_reverse_degrees(uint16_t degrees, uint8_t speed_percent)
//{
//    printf("[DEBUG] motor_reverse_degrees called\n");
//    printf("[DEBUG] Degrees: %u\n", degrees);
//
//    encoder_count = 0;
//    int32_t target_ticks = ((degrees * PULSES_PER_REV) + 359) / 360;
//    printf("[DEBUG] Target Ticks: %ld\n", target_ticks);
//
//    motor_set_speed(speed_percent);
//    HAL_GPIO_WritePin(motor_dir_port, motor_dir_pin, GPIO_PIN_RESET);
//
//    printf("before look\n");
//
//    while (-encoder_count < target_ticks) {
//        printf("ENC: now=%ld, target=%ld\n", encoder_count, target_ticks);
//    }
//
//    motor_stop();
//    printf("[DEBUG] motor_stop() called. Final encoder count: %ld\r\n", encoder_count);
//}

void motor_reverse_degrees(uint16_t degrees, uint8_t speed_percent)
{
    printf("[DEBUG] motor_reverse_degrees called\n");

    encoder_count = 0;

    motion.target_ticks = ((degrees * PULSES_PER_REV) + 359) / 360;
    motion.direction = -1;
    motion.speed = speed_percent;
    motion.active = 1;

    HAL_GPIO_WritePin(motor_dir_port, motor_dir_pin, GPIO_PIN_RESET);
    motor_set_speed(speed_percent);

    printf("[DEBUG] Target Ticks: %ld\n", motion.target_ticks);
}

void motor_stop(void)
{
    motor_set_speed(0);
}

void motor_encoder_update(uint8_t ch_a_state, uint8_t ch_b_state)
{
    static uint8_t last_state = 0;
    uint8_t current_state = (ch_a_state << 1) | ch_b_state;

    uint8_t transition = (last_state << 2) | current_state;
    last_state = current_state;

    // Standard quadrature decoding transitions
    switch (transition)
    {
        case 0b0001:
        case 0b0111:
        case 0b1110:
        case 0b1000:
            encoder_count++;  // Forward
            break;
        case 0b0010:
        case 0b0100:
        case 0b1101:
        case 0b1011:
            encoder_count--;  // Reverse
            break;
        default:
            // Invalid transition or no movement
            break;
    }

    // Optional for debug
//     printf("[ENC UPDATE] Count = %ld\n", encoder_count);
}


uint32_t motor_get_rpm(void)
{
    uint32_t now = HAL_GetTick();
    uint32_t elapsed = now - last_encoder_time;
    if (elapsed == 0) return 0;

    int32_t delta = encoder_count - last_encoder_count;
    last_encoder_count = encoder_count;
    last_encoder_time = now;

    // Assume 11 pulses per revolution (PPR from Hall encoder doc)
    return (delta * 60000) / (11 * elapsed);  // RPM = (delta * 60s * 1000ms/s) / (PPR * time_ms)
}

void motor_update(void)
{
    if (!motion.active) return;

    int32_t current = encoder_count;

    if (
        (motion.direction == 1 && current >= motion.target_ticks) ||
        (motion.direction == -1 && -current >= motion.target_ticks)
    ) {
        motor_stop();
        motion.active = 0;

        printf("[DEBUG] Motion completed. Final encoder: %ld\n", encoder_count);
    }
}

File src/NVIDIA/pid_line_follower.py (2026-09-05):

"""
pid_line_follower.py  --  keep the car centered on the track using L/R sensors.

Reads the left and right side distances, computes how far the car is from the
track centerline, and runs a PID controller to produce a steering correction
(in servo microseconds) that re-centers the car.

Error definition (width-independent):
    error = (right_mm - left_mm) - center_offset

    - Centered  -> left == right -> error ~ 0
    - Car drifts toward the LEFT wall  -> left shrinks, right grows -> error > 0
    - Car drifts toward the RIGHT wall -> error < 0

    Using the DIFFERENCE (not the sum) means it works for both the 1000 mm and
    600 mm corridors without changes.

Output:
    steering_us = steer_sign * PID(error), clamped to +/- out_limit.
    steer_sign flips the direction if your servo's sign is opposite (test once:
    push the car toward the left wall; the correction should steer it right).

Invalid readings (sensor not ready, 0, or > max_valid_mm, e.g. a wall gap at a
corner) freeze the integrator and return the last command so the car does not
jerk on a bad sample.

HEADING (optional, kh > 0)
    The error above is a POSITION. A car can sit exactly on the centreline while
    pointed 30 degrees across it, and this controller reads that as zero error --
    which is why it recovers from a corner exit so slowly: it has to wait for the
    angle to TURN INTO a position error before it reacts at all, and by then it
    is already at the wall.

    The two right-side sensors measure the angle directly. Parallel to the wall,
    RF and RR read the same (plus a fixed mounting offset); nose swung away from
    the wall, RF > RR. Feeding that in as a second term makes this a controller
    on where the car IS *and* where it is POINTED:

        u = steer_sign * (kp*err + ki*int + kd*d/dt + kh*heading)

    Same sign convention throughout: positive u steers TOWARD the right wall,
    and heading > 0 (nose away from the right wall) asks for exactly that.

    THE OFFSET IS LEARNED, NOT MEASURED. RF - RR is only zero when the two
    sensors are perfectly aligned, and bench readings of a "parallel" car came
    out +152, +174 and -46 depending on the pose -- the measurement was of the
    pose, not the mounting. So the offset is instead learned while driving: on a
    straight, with the car centred and the steering quiet, RF - RR IS the
    mounting offset by definition. Until enough of those samples exist the
    heading term stays exactly 0, so an uncalibrated car behaves as it did
    before.
"""

import statistics
import time
from collections import deque


class LineFollowerPID:
    def __init__(
        self,
        kp: float = 0.30,
        ki: float = 0.00,
        kd: float = 0.10,
        out_limit: float = 150.0,
        center_offset: float = 0.0,
        steer_sign: int = 1,
        max_error: float = 400.0,
        deadband: float = 8.0,
        max_valid_mm: float = 2000.0,
        integral_limit: float = 300.0,
        median_window: int = 3,
        slew_limit: float = 0.0,
        kh: float = 0.0,
        rr_offset: float = 0.0,
        offset_ref_mm: float = 0.0,   # 0 = treat rr_offset as a fixed gap
        heading_max: float = 200.0,
        learn_offset=None,       # None = learn only if no offset was given
        learn_error_mm: float = 80.0,
        learn_steer_us: float = 55.0,
        learn_quiet_frames: int = 3,
        learn_samples: int = 12,
        learn_window: int = 41,
    ):
        self.kp = kp
        self.ki = ki
        self.kd = kd
        self.out_limit = out_limit
        self.center_offset = center_offset
        self.steer_sign = steer_sign
        self.max_error = max_error
        self.deadband = deadband
        self.max_valid_mm = max_valid_mm
        self.integral_limit = integral_limit
        # Input noise rejection: median over the last N valid samples per side.
        self.median_window = max(1, int(median_window))
        # Output slew-rate limit: max change in steering_us per update (0 = off).
        self.slew_limit = slew_limit
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

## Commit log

2026-02-03 change camera parameters
2026-02-15 STM32 src code updated
2026-02-15 add other datasheet and flowchart
2026-03-30 motor drv fixed
2026-06-06 Add files via upload
    Changes in main: Motor movement and button code
2026-06-06 Communication Program via TTL with the stm32
2026-06-06 Servo control program
2026-06-22 docs: add WRO engineering journal
    Add the Engineering Journal for the MetallicMadness / ARBIBOT WRO Future Engineers project.
    This commit includes:
    Markdown version of the Engineering Journal
    PDF version for review and judging
    Supporting image assets used in the journal
    Local README explaining the purpose and structure of the engineering-journal folder
    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
2026-06-22 docs: add power and sensor architecture
    Added power and sensor architecture documentation for ARBIBOT, including motor and Jetson power paths, BMS and UPS usage, estimated current draw, wiring organization, grounding considerations, VL53 sensor placement, I2C/XSHUT address management, calibration procedure, and subsystem failure modes.
2026-06-22 docs: add software architecture documentation
    Added software architecture documentation for ARBIBOT, including the Jetson and STM32 responsibility split, main Python and firmware modules, DD-UART protocol, command flow, state machine, Open Chall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
2026-06-22 docs: add obstacle challenge strategy
    Added Obstacle Challenge strategy documentation for ARBIBOT, including red/green pillar pass-side logic, YOLO detection pipeline, nearest-pillar selection, lane-following behavior, PDI steering contr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
2026-06-22 docs: add testing and tuning documentation
    Added testing and tuning documentation for ARBIBOT, including test run logs, lap-time and success-rate templates, motor and sensor validation, YOLO testing, Open and Obstacle Challenge test matrices, failure analysis, tuning parameters, runtime checks, and next testing priorities.
2026-06-22 docs: add system diagrams for schemes folder
    Add engineering diagram documentation under schemes/.
    Included files:
    - arbibot_2026_electronics_and_control_architecture.png
    - full-wiring-diagram.png
    - power-distribution-diagram.png
    - sensor-placement-diagram.png
    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
2026-06-22 docs: add Open Challenge video evidence
    Added Open Challenge video evidence for ARBIBOT, including challenge01.mp4 and a README explaining the purpose of the video folder, current video evidence, naming conventions, and future challenge vi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
2026-06-22 docs: add vehicle photos documentation
    Added real vehicle photos for ARBIBOT, including back, left, right, top, and front-bumper views. Also added a README for the v-photos folder explaining the purpose of each image, how they support WRO documentation, current photo coverage, missing required views, and recommended future close-up photos.
2026-06-22 docs: add systems thinking and engineering decisions
    Added systems thinking and engineering decision documentation for ARBIBOT, including subsystem trade-offs, rejected alternatives, architecture decisions, failure-driven improvements, risk analysis, power and sensor decisions, software strategy decisions, and remaining data needed for final validation.
2026-06-22 docs: add risk register and failure modes
    Added a detailed risk register for ARBIBOT, documenting major failure modes such as glare, bad pillar detection, sensor noise, UART timeouts, motor command blocking, weak battery, stop-command failure, wheel slip, steering misalignment, and parking risk. The document includes probability/impact scoring, mitigation plans, detection methods, recovery behavior, test checklists, and final evidence needed to close each risk.
2026-06-22 docs: add bill of materials
    Added a Bill of Materials for ARBIBOT, documenting the main mechanical, electronic, power, sensor, compute, motor, and communication components. The document includes each component’s function, volta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
2026-06-22 docs: add protocol folder documentation
    Added protocol folder documentation for ARBIBOT, including a README that explains the purpose of the DD-UART communication folder, active command IDs, frame format, checksum rules, example frames, im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
2026-06-22 docs: add vision models documentation
    Added trained vision model files for ARBIBOT and documented the Models folder. The README explains the purpose of each YOLO checkpoint, expected use for pillar and corner detection, related Python sc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
2026-06-22 docs: update power architecture and runtime analysis
    Updated ARBIBOT power documentation using the final two-battery architecture: Waveshare UPS for logic/steering and a separate 3S motor battery through the BMS and Cytron MD10C for the drive motor. Added traced component loads, 5V rail validation, runtime estimates, motor battery margin, and the remaining peak-current sag verification item.
2026-06-23 docs: update vehicle photos with motor and steering views
    Updated the vehicle photos folder with PNG image references for the complete vehicle view set, front bumper close-up, installed motor and steering mechanism, and drive motor component reference. The 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
2026-06-23 docs: update final engineering journal
    Updated the final WRO Engineering Journal for MetallicMadness / ARBIBOT in both Markdown and PDF formats, including the latest mechanical measurements, power budget, sensor mapping, YOLO11n training 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
2026-06-23 docs: update models README with final YOLO details
    Updated the Models README with confirmed YOLO11n model roles, active model files, class names, dataset sizes, training configuration, Jetson inference speed, confidence thresholds, and current model 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
2026-06-23 docs: refresh engineering documentation with current robot data
    Updated the ARBIBOT engineering documentation with current confirmed project information, including mechanical measurements, power budget, sensor mapping, YOLO11n model details, dataset sizes, testing metrics, calibration status, BOM values, and risk-register updates. Removed outdated TODO placeholders and replaced unavailable raw calibration values with honest future-measurement notes.
2026-06-24 docs: update models README with chassis CAD files
    Updated the Models README to document the new CAD chassis files in Models/cad, including the bottom, middle, and top STL layers of the ARBIBOT three-layer chassis design. The README now explains the 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
    [Chasis_Bottom.stl, Chasis_Middle.stl, Chasis_Top.stl]
2026-06-25 feat: update Jetson NVIDIA control scripts
    Updated the Jetson/NVIDIA control code for ARBIBOT, including camera color tuning, main runtime logic, motor driver commands, PID line following, sensor distance handling, servo control, and turn/cor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
2026-06-26 feat: add WRO main systemd service documentation
    Adds a systemd service setup for the NVIDIA robot runtime and documents how to manage it during development and competition preparation.
    Changes included:
    Added wro-main.service for boot-time execution of main.py
    Added service README with installation, logging, permission, and debugging commands
    Documented safe competition startup flow using the physical Start button
    Ignored macOS .DS_Store files from Git tracking
2026-06-26 feat: add runtime logging to NVIDIA main program
    - Added file-based runtime logging for the robot main process
    - Added console/stdout logging support for systemd compatibility
    - Logged startup, initialization, waiting state, Start button, shutdown, and error events
    - Added exception logging with traceback support
    - Improved visibility when running the robot automatically as a service"
    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
    [main.py]

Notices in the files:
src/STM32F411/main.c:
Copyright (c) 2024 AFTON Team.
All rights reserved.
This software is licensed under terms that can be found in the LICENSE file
